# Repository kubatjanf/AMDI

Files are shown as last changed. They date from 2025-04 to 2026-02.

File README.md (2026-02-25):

# Low-Cost Autonomous 3D-Printed Mini Disk Infiltrometer (AMDI)
Fore detailes refer to [Journal of Hydrology](doi.org/10.1016/j.jhydrol.2025.134212)

## Introduction

The **Automated Mini Disk Infiltrometer (AMDI)** is a 3D-printed, low-cost device designed to measure **soil infiltration** under controlled suction conditions. Based on the principles of the widely used **Mini Disk Infiltrometer (MDI)**, the AMDI extends its functionality by integrating a **TMS-4 capacitance sensor** for automatic data collection, reducing the need for manual observation.

The AMDI is suitable for both **field** and **laboratory** use and enables the estimation of **unsaturated hydraulic conductivity** near saturation.

🚨 **Place order via email at jan-frantisek.kubat@fsv.cvut.cz or michal.snehota@cvut.cz. This offer is valid until withdrawn.**

---

## Future

To further establish the AMDI as a go-to instrument, the following steps are necessary to ensure a smooth user experience and maintain data integrity:

- Develop a software interface for calibration and measurement evaluation.
- Design a simpler calibration method that remains equivalent in accuracy but is more cost-effective.
- Conduct intensive field testing and implement modifications based on the collected data.
- Negotiate with TOMST company to integrate a native AMDI option into the TMS-4 software. 

---

## AMDI Overview

The following figure presents the fully assembled AMDI:

AMDI

---

## 3D Printing Overview

All 3D-printed parts were created using FDM printers such as **Prusa XL**, **MK3S+**, or **Mini+**. Recommended print settings are available in the provided `SlicerSettings.3mf` file.
AMDI was tested with polyethylene terephthalate glycol (PET-G) filament produced by Prusa a.s. (Czechia).
Use clear filament (color: E4E7E5) with a diameter of 1.75 ± 0.02 mm. Since the suction is set by adjusting the water level in the Mariotte chamber.

| Parameter | Value |
|---|---|
| Layer height | 0.1 to 0.15 mm |
| Extrusion multiplier | 1.1 |
| Max print speed | 15 mm/s |
| Printing temperature | 260 °C |
| Wall thickness | 2.5 mm |
| Infill | 100% |
| Cooler speed | 15 to 20% |
| Retraction length | Disabled |
| Infill/perimeters overlap | 20% |

---

## Required Components

- **O-rings**:
  - 1× 45 × 3.6 mm  
  - 1× 5 × 2.0 mm  
  - 3× 20 × 3.6 mm  

- **Other parts**:
  - 1× TMS-4 TDT sensor [shop](https://tomst.com/web/en/systems/tms/tms-4/)
  - 1× Sintered stainless steel disk (Ø 45 mm, 3 mm thick)  
  - 3D printed parts:
    - A1 + A2 (infiltrometer body and base)
    - B1 + B2 (Mariotte chamber and suction tube)
    - C (lid)

---

## Assembly Instructions

1. **Bond Printed Parts**  
   - Glue A1 to A2, B1 to B2, and C to the disk using suitable adhesive.  
   - Allow to cure for 24 hours.

2. **Install O-rings and Sensor**  
   - Place O-rings into designated grooves.  
   - Lubricate before inserting the sensor to avoid damage.

3. **Assemble the Mariotte Chamber**  
   - Connect to the main body via O-ring seals.  
   - Use the integrated scale to adjust suction height.

4. **Final Assembly**  
   - Mount the chamber to the body rails using the sliders.  
   - Fill with water (approx. 150 mL), seal with the lid, and ensure no leakage.

> You can refer to the AI Assistant for help with assembly, calibration, and initial measurements: [AMDI AI-Assist](https://chatgpt.com/g/g-686f85880f7c81918232c61168e00342-amdi-ai-assistant).
> Assist is based on OpenAI ChatGPT.

---

## Calibration

Each AMDI device requires **individual calibration** to relate raw sensor signals to actual water volume. This ensures accurate measurement of infiltration.

General calibration steps:

1. Fill the reservoir and record weight loss over time on a precision balance.
2. Log the TMS-4 sensor signal simultaneously.
3. Fit the paired data using a polynomial regression (e.g., cubic).
4. Use only the active sensing region to avoid artifacts.

> Calibration details, procedures, and equations are available in the associated publication.

---

## Infiltration Measurements

The AMDI can be used under controlled or natural conditions to monitor infiltration at various pressure heads. The sensor enables automated data logging, making it suitable for both short-term and long-term infiltration studies.
Macro to calculate hydraulic conductivity: provied by MeterGroup [Macro](https://library.metergroup.com/Sales%20and%20Support/METER%20Environment/New-Minidisk-Infiltrometer-Macro.xlsx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)

> Refer to the associated article for detailed procedures and data analysis workflows.

---

## Modification

Modification is highly encouraged but must be credited. If feasible, please initiate a branch with the modification for review.

For example, it is not necessary for the Mariotte chamber (part B) to be detachable.

---

## Citation

If you use the AMDI in your work, please cite the related publication: [Article](https://doi.org/10.1016/j.jhydrol.2025.134212)

> Jan-František Kubát, Francesco Zanna, Martin Mildner, Michal Sněhota, (2025). Low-Cost Autonomous 3D-Printed Mini Disk Infiltrometer. Journal of Hydrology, DOI: doi.org/10.1016/j.jhydrol.2025.134212

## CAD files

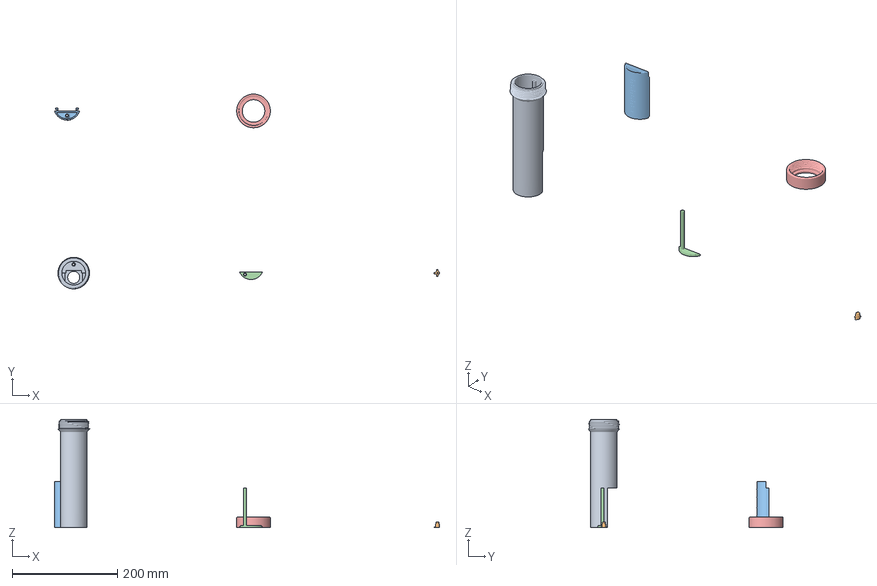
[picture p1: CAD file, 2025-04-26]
SlicerSettings.3mf
731.1 x 369.9 x 205.5 mm
A1_BodyFinal.stl
A2_Connector(Nozzle)Final.stl
B1_MariotteChamberFinal.stl
B2_SuctionTubeFinal.stl
C_BottomLidFinal.stl

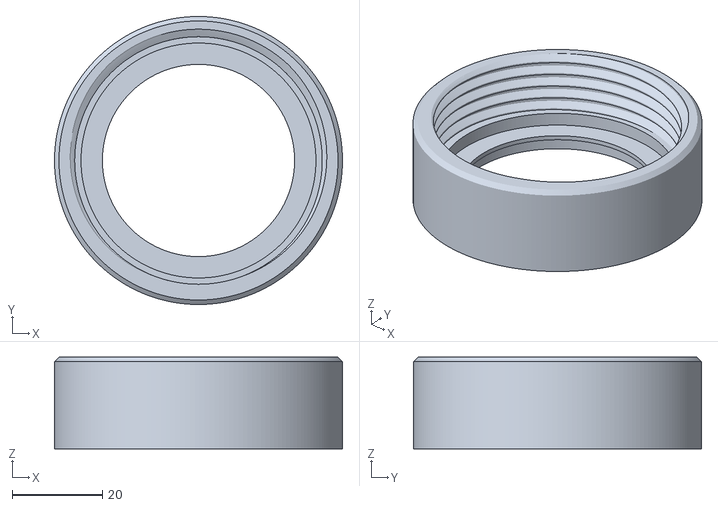
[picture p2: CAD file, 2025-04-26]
C_BottomLidFinal.stl
64.0 x 64.0 x 20.4

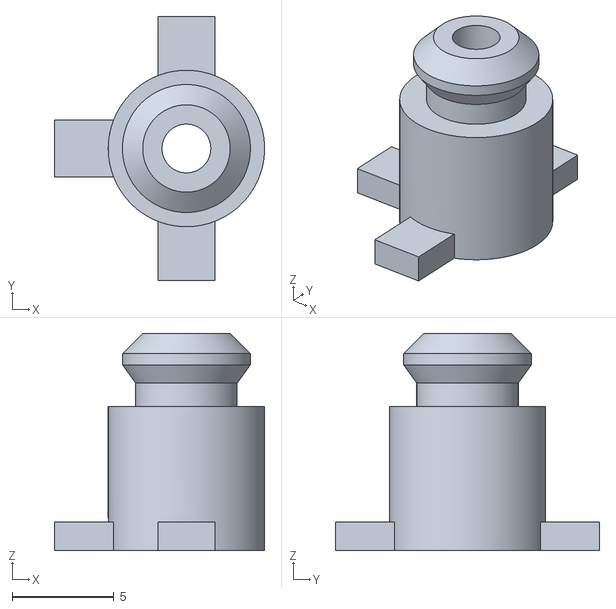
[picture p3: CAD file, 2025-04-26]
A2_Connector(Nozzle)Final.stl
10.3 x 13.0 x 10.7

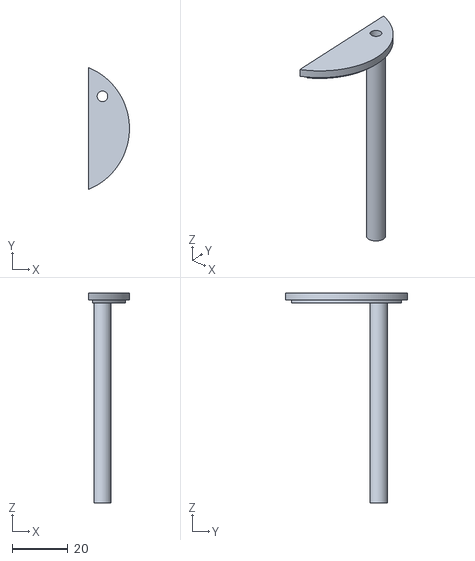
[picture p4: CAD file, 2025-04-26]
B2_SuctionTubeFinal.stl
14.7 x 43.8 x 75.5

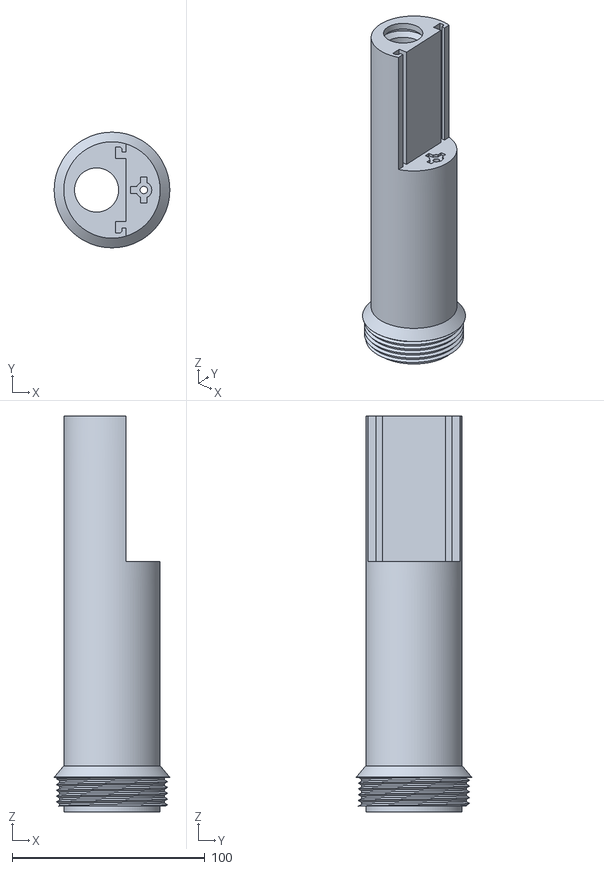
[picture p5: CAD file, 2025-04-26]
A1_BodyFinal.stl
60.0 x 60.0 x 205.5

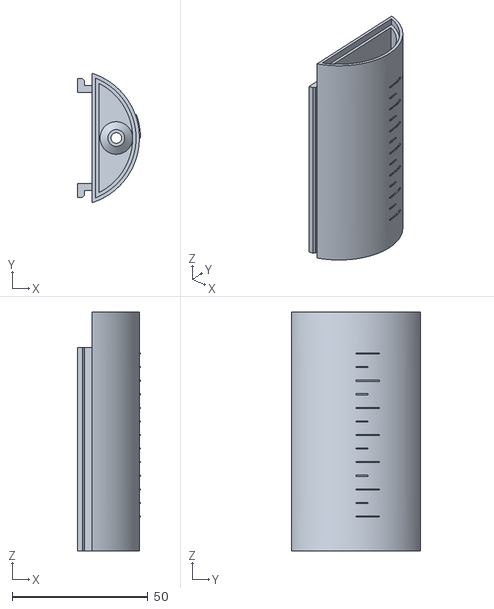
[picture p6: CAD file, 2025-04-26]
B1_MariotteChamberFinal.stl
23.2 x 47.6 x 88.0

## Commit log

2025-04-26 Mini disk infiltrometer parts v1.0
    [A1_BodyFinal.stl, A2_Connector(Nozzle)Final.stl, B1_MariotteChamberFinal.stl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]
2025-04-26 General Slicer Setting
    Include positions of each part, alteration may compromise the desired properties.
    [SlicerSettings.3mf]
